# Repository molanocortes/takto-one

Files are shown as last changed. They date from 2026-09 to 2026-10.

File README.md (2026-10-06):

<div align="center">

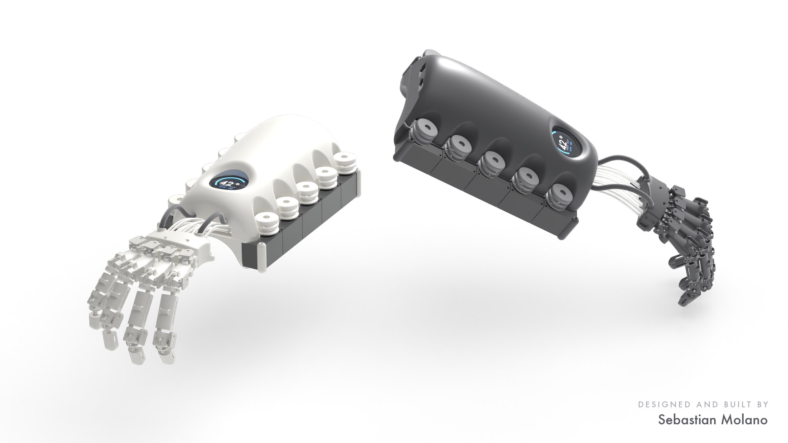
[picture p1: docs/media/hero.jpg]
TAKTO ONE


# TAKTO ONE

### Open hand control. Read every finger. Drive every finger.

TAKTO ONE is an open-source hand exoskeleton: it reads twelve finger joints at the joint
itself and pulls them back through tendons, with the control loop on the device, not on a laptop. Wear it and your hand becomes an
instrument: every motion measured, recorded, and answered with force. This repository is
every file needed to build one.

**[takto.one](https://takto.one)**, the official website: the device in 360°, the live digital
twin and the console, right in your browser.








</div>

---

<!-- The film: a poster image linking to a GitHub attachment URL. This is the ONE form that
     works on desktop web AND in the GitHub mobile app, verified 2026-09-04. How the others fail:
       - a <video> tag is stripped by GitHub's sanitiser everywhere; only what is inside survives
       - a bare user-attachments URL on its own line becomes an inline player on desktop web only;
         the mobile app renders it as a plain link
       - a relative link to the in-repo .mp4 opens the blob player on desktop, dead tap in the app
     The attachment is served as video/mp4 with no download disposition, so tapping plays natively.
     docs/media/TAKTO-ONE.mp4 is the durable in-repo copy (v057). The URL below was minted by
     dragging that file into a comment on PR #1 and POSTING the comment: attachments dragged in but
     never posted are garbage-collected, which is how the two previous URLs died. To update the film:
     replace the in-repo file, drag the new one (under 10 MB) into a comment on PR #1, post it,
     verify the URL logged out, then swap it here. -->

<div align="center">
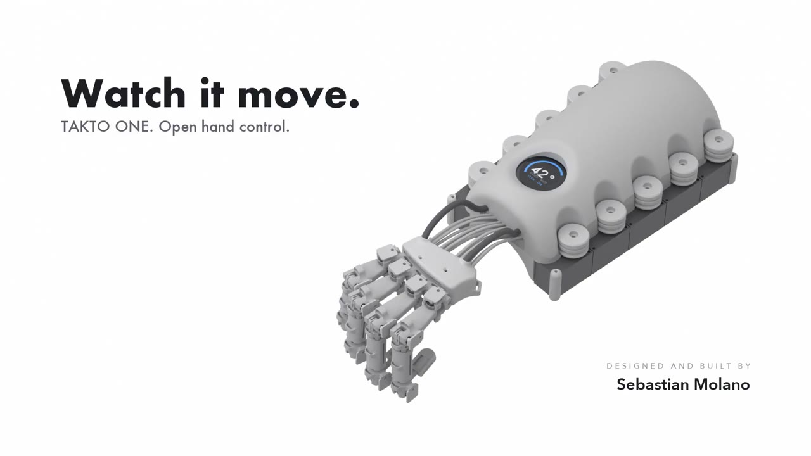
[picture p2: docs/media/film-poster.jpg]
Watch the film: TAKTO ONE turning in the white studio
  
</div>

---

<div align="center">

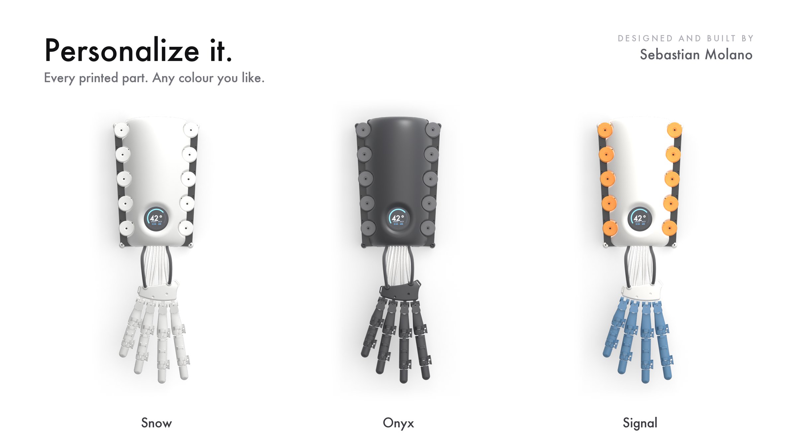
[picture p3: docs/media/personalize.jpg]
Personalize it, three colourways


</div>

---

## Why a hand, and why this one

Your hand is the highest-bandwidth interface you own, and machines still read it badly. A
camera loses fingers the moment they cross, curl, or leave frame. A glove full of flex sensors
drifts. TAKTO ONE puts a magnetic encoder on the joint itself, three per finger, twelve in
all, so the measurement ignores occlusion, lighting, and where you happen to stand. And
because the microcontroller owns the motor bus, the device acts without a computer in the loop.

Per-joint truth going in, tendon force coming out, no host required. It is a hand-shaped input
and output device, and what you point it at is up to you.

## What it already does

Two of the most useful things a hand platform can do are built and in this repository.

**Motion capture that writes to the device, not to a browser.** The firmware logs to the
Teensy's own SD card, one row per frame: all fourteen encoder channels, the hand, forearm and
thumb quaternions, EMG envelope and RMS, the crown, and full motor telemetry. One sensor
acquisition feeds the SD row, the serial stream and the display, so the log and the live view
can never disagree. The rate is a firmware constant, not a display refresh. The result is
serious hand-motion data: per-joint, occlusion-free, timestamped, labelled by physics instead
of by another model's guess.

**Teleoperation and assistance.** The control law runs on the Teensy in three modes: idle,
direct current, and a blend that moves continuously between *transparent*, where the device
follows the wearer and stays out of the way, and *assist*, where it drives toward a setpoint.
The blend is a live parameter, so the hand can lead the device, the device can lead the hand,
or anything in between. Setpoints, gains and current limits are all exposed over the serial
protocol, which is what lets one hand drive another.

Together they close the loop that matters: read a hand precisely, record it, and play it back
into a hand.

---

## Two custom boards

Designed from scratch in KiCad for this device and published in full: schematic, layout and
manufacturing outputs for each board are in [`electronics/`](electronics/). The renders come
straight from those files.

<table>
<tr>
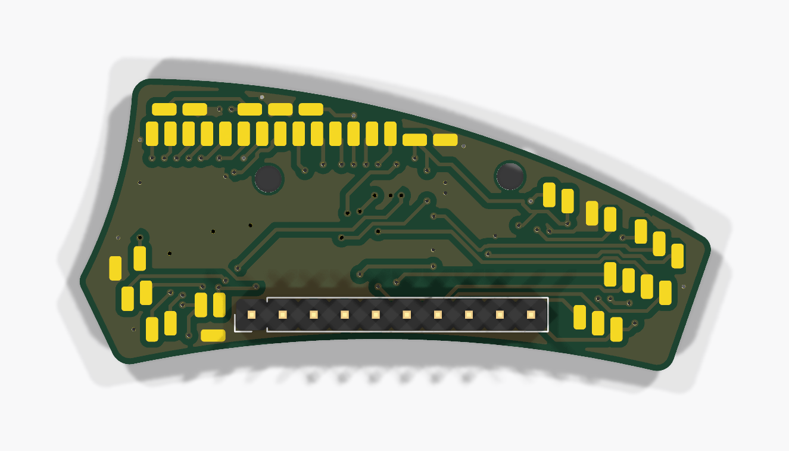
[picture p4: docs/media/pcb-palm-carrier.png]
Palm carrier board, KiCad 3D render
<td width="58%"></td>
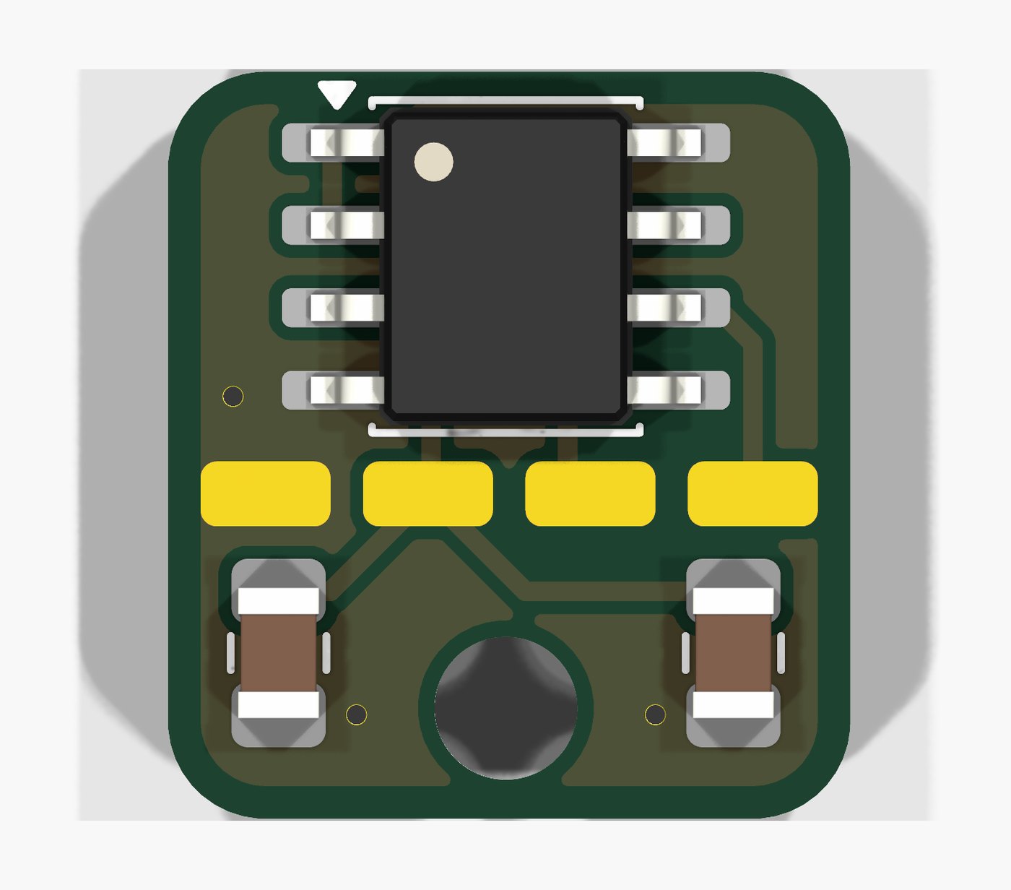
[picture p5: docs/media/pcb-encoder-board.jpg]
Encoder board, KiCad 3D render
<td width="42%"></td>
</tr>
<tr>
<td align="center"><b>Palm carrier</b></td>
<td align="center"><b>Encoder board</b></td>
</tr>
</table>

- **Palm carrier** (`palm_carrier/`). Shaped to the curved palm plate. Two TCA9548A I²C
  multiplexers fan the bus out to fourteen encoder channels: twelve joints, plus two reserved
  for a thumb.
- **Encoder board** (`encoder_board/`), one per joint. An AS5600 magnetic angle sensor centred
  under a through-board aperture, so the joint's magnet sits on the sensor's axis.

Both were fabricated and assembled in one JLCPCB order (June 2026, USD 170.73 delivered),
itemised in the [bill of materials](docs/BOM.md).
One known erratum, documented rather than hidden: on the palm carrier the second multiplexer's
SDA and SCL net labels are swapped on channels 8 to 13, so those six channels are wired
crossed. [`electronics/README.md`](electronics/README.md) has the detail. The 74HC241 servo-bus
interface is separate from these boards; its pins are in the firmware and in the wiring below.

## How it fits together

Sensing → aggregation → control → interface:

System architecture

And the full point-to-point wiring: every pin terminated, both I²C multiplexers, all fourteen
encoder channels, all three IMU positions, and the 74HC241 servo bus. The
[PDF](docs/global-wiring.pdf) is the printable version.

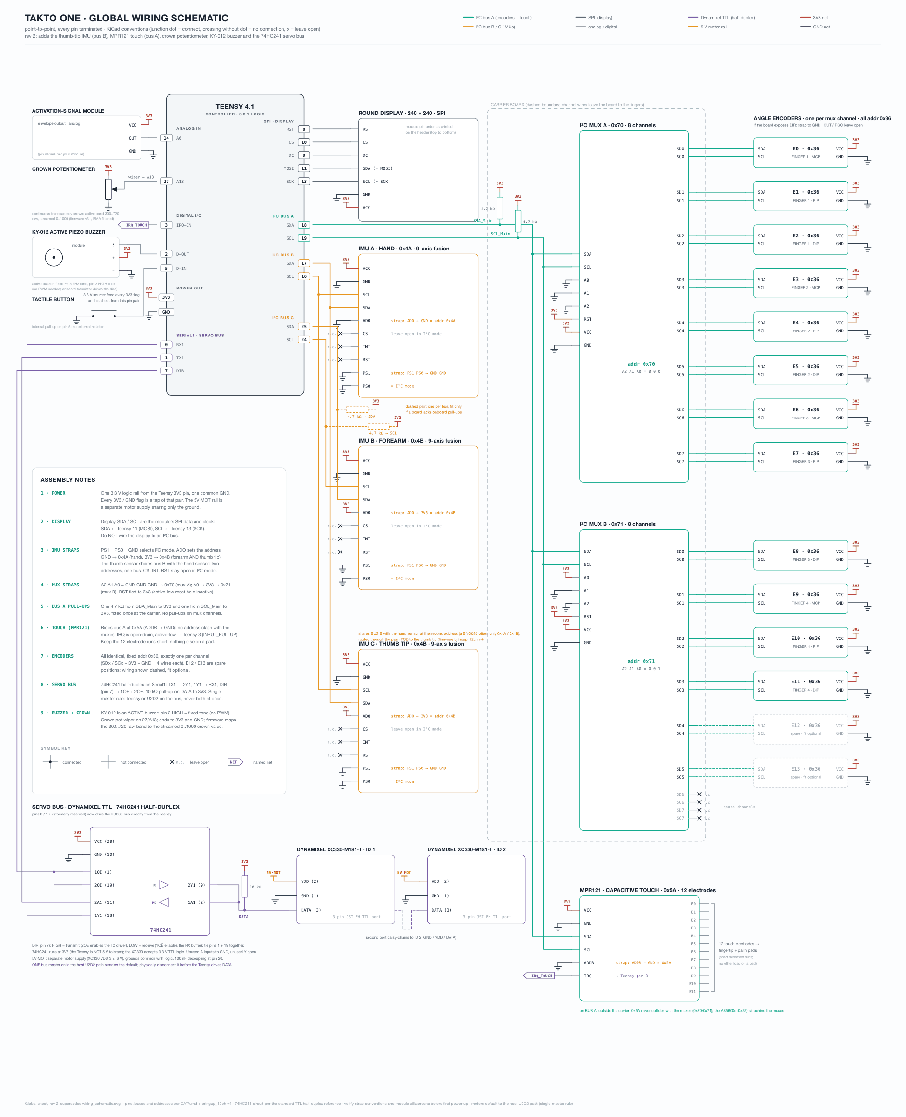
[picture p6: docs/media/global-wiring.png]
Global wiring schematic


---

## Session replay: motion, played back in space

Record a hand once and it replays anywhere the twin runs. The viewer rebuilds the session as a
4D scene: the real device GLB articulated by the twelve recorded joint angles, the wrist flying
the 6-DoF path the headset measured, the room drawn from the environment mesh stored with the
take, and the flexion and effort traces under the scrubber. Any speed, any angle, forever.

<!-- Loops on phones. GitHub loads every image in a README at once (it strips loading="lazy"),
     and the five GIFs on this page weigh 16 MB. The GitHub Android app also cannot show a README
     with a GIF in it: the page flickers on every frame and reads as empty (github.com/orgs/
     community/discussions/158337), and the app ignores <source>. So each loop is a <picture>
     whose <img> is a still frame (docs/media/<name>-still.*), which phones, the app and
     reduce-motion readers get, and whose <source> hands the GIF only to a wide screen with a
     mouse; a tap on the still opens the loop. Keep "prefers-color-scheme" out of that media
     query: GitHub's <themed-picture> rewrites any <source> that mentions it. -->

<div align="center">

<a href="docs/media/ui-replay.gif">
<picture>
  <source media="(min-width: 768px) and (pointer: fine) and (prefers-reduced-motion: no-preference)" srcset="docs/media/ui-replay.gif">
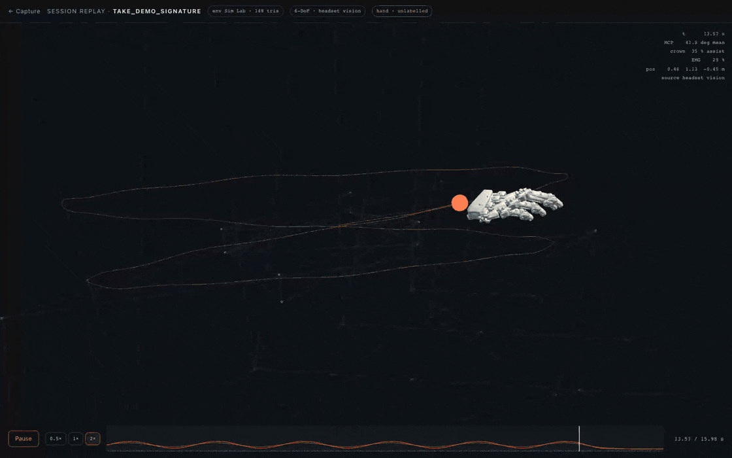
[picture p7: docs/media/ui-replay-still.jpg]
A recorded take replaying: the device hand banking along its full trajectory ribbon through a wireframe room, with live joint, effort and position read-outs
  
</picture>
</a>

<sub><b>take_demo_signature</b>, played at 2× in the shipped viewer. One of three sample takes
in [`software/bridge/samples/`](software/bridge/samples/) — choreographed, synthetic, and
generated by a script that ships beside them. Three commands and this plays on your machine
with no hardware.</sub>

</div>

The format is the same one the device writes to its SD card, so your own recordings drop
straight in. The environment store is wired end to end, but dense room reconstruction from the
Quest 3S is still open work: the viewer, the store and the upload path are all waiting for it,
and putting a real scanned room behind these trajectories is one of the most satisfying
contributions this project has to offer. See [Contributing](#contributing).

---

## LUMEN: the AR layer

**Source included:** [`software/ar/`](software/ar/)

A spatial layer that puts the hand twin and its data into the room instead of on a monitor.
It reads the same WebSocket stream as the console, needs no separate backend, and runs in a
plain browser on the desktop, which is how the frames below were captured.

<div align="center">

<a href="docs/media/ar-modes-live.gif">
<picture>
  <source media="(min-width: 768px) and (pointer: fine) and (prefers-reduced-motion: no-preference)" srcset="docs/media/ar-modes-live.gif">
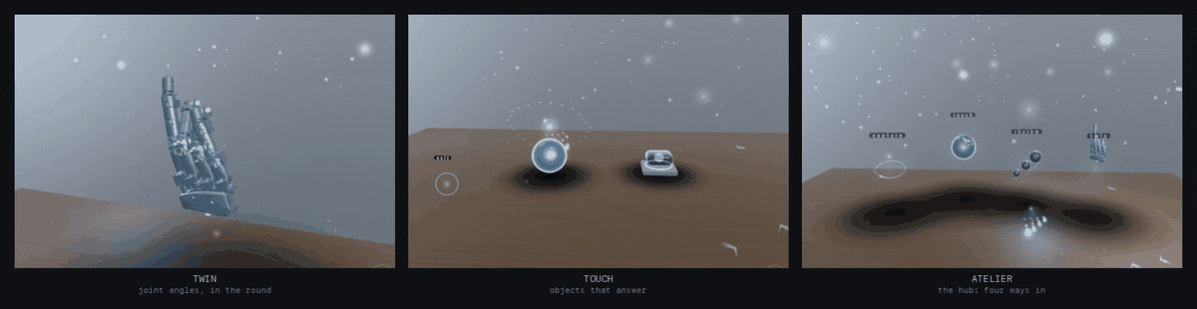
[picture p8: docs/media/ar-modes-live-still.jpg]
Three modes of the AR layer running: the hand twin seen from a moving viewpoint, a touch object deforming under contact, and the atelier hub with its four reachable objects
  
</picture>
</a>

<sub>Running live in the desktop preview: <b>twin</b>, the articulated hand driven by joint
angles and seen from a moving viewpoint &nbsp;·&nbsp; <b>touch</b>, objects that answer the wearer's fingers &nbsp;·&nbsp;
<b>atelier</b>, the hub, where the four modes are objects you reach toward rather than buttons.
Butterflies drift through every one of them.</sub>

</div>

Five modes ship: `atelier` as the hub, plus `twin`, `touch`, `rhythm` and `capture`. The scene
carries the device's own geometry, so what you reach toward is the machine on your arm. It is
also inhabited: butterflies wander the room, settle on the desk edge to rest their wings, and
lift off again, and rare comets cross the upper air. None of it competes with the work; it just
means the space is alive while you are in it.

> **Prototype, captured on the desktop preview** rather than in a headset. Known high-DPI bug:
> the render target is sized from CSS pixels while the canvas backs at the device ratio, so on
> a 2x display the scene draws into a quarter of the canvas. Force a device pixel ratio of 1 as
> a workaround; fixing it properly is a good first contribution.

---

## The phone companion

**Source included:** [`software/app/`](software/app/)

A pocket instrument for the times the laptop is not the right one: watch the twin, replay a
recorded session, and read the twelve joints and the activation channel, from the same stream
and protocol as everything else here. One Expo codebase for iOS, Android and the browser.

<div align="center">

<a href="docs/media/app-live.gif">
<picture>
  <source media="(min-width: 768px) and (pointer: fine) and (prefers-reduced-motion: no-preference)" srcset="docs/media/app-live.gif">
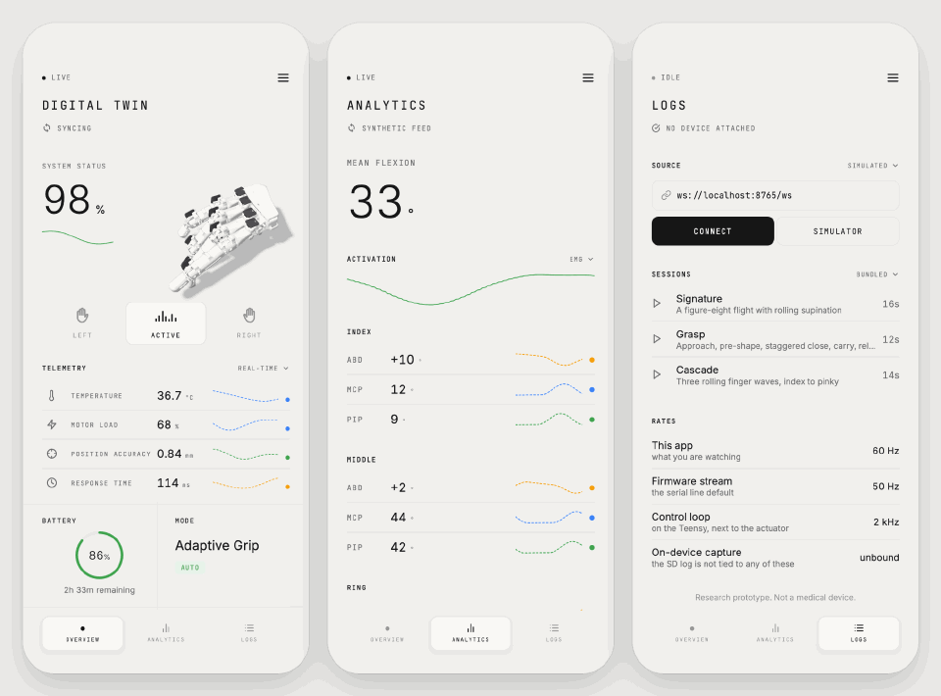
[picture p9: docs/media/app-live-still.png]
The companion app running: Overview, Analytics and Logs side by side on one clock, the twin curling finger by finger while the joint read-outs and the effort trace follow
  
</picture>
</a>

<sub><b>Overview</b>, the device at a glance &nbsp;·&nbsp; <b>Analytics</b>, the twelve joints and
the activation channel &nbsp;·&nbsp; <b>Logs</b>, the source, the bundled sessions and the rates</sub>

<sub>The travelling wave, index to pinky, on the synthetic feed. Twelve joints driven
independently, and all three surfaces pinned to the same clock: one instant of the app, not
three screens shot at three different moments.</sub>

</div>

The twin is the real CAD driven by the shared mechanical model in
[`kinematics.js`](software/app/src/data/kinematics.js): the angles, the telescopic slides those
angles demand, and the spool rotations that produce them. It runs with no hardware at all on
the same synthetic feed as every other surface, and the three bundled sessions are the
repository's own sample takes. Point it at a bridge and it reads a real device.

An earlier Android-only build is superseded by this one; its emulator captures are gone from
this page.

---

## The device screen

The Teensy drives a round display, and the face engine that paints it is part of the firmware.
One face ships, **thesis**, in three colourways (Sapphire Depth, Graphite and Amber), and it
covers every device state: battery, boot, calibrate, fault, idle, linked, recording, saved,
standalone, stop and teleop. Two earlier design studies, **rams** and **ferro**, stay in the
source for reference; they are not built into the firmware.

**None of these are static screens.** Every face animates: boot sweeps and self-tests, the
teleop ring tracking assist, the recording counter and its take meter, idle breathing while
nothing is happening. The engine runs a dirty-tile renderer inside a fixed frame budget, so the
paint never starves the control tick.

<div align="center">

<a href="docs/media/watch-faces-live.gif">
<picture>
  <source media="(min-width: 768px) and (pointer: fine) and (prefers-reduced-motion: no-preference)" srcset="docs/media/watch-faces-live.gif">
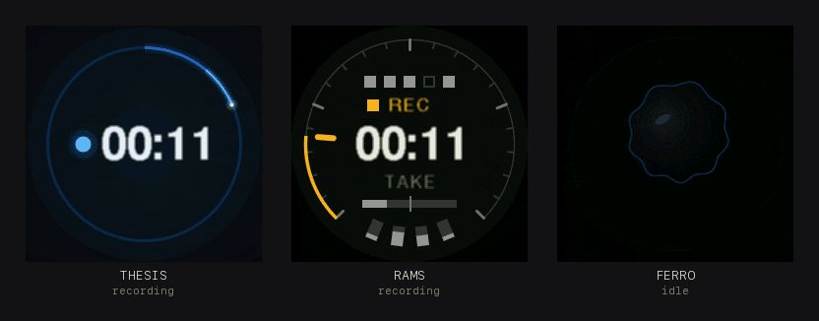
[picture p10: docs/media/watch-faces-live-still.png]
The thesis face and the two design studies animating: boot sequences, then recording counters and an idle face in motion
  
</picture>
</a>

<sub>Faces rendered by the firmware's own rasterizer from a mock feed and played at the speed
they were authored: the boot sequence of the shipping <b>thesis</b> face and of the two studies,
then <b>recording</b> counting a take up, and <b>idle</b> breathing.</sub>

</div>

<div align="center">

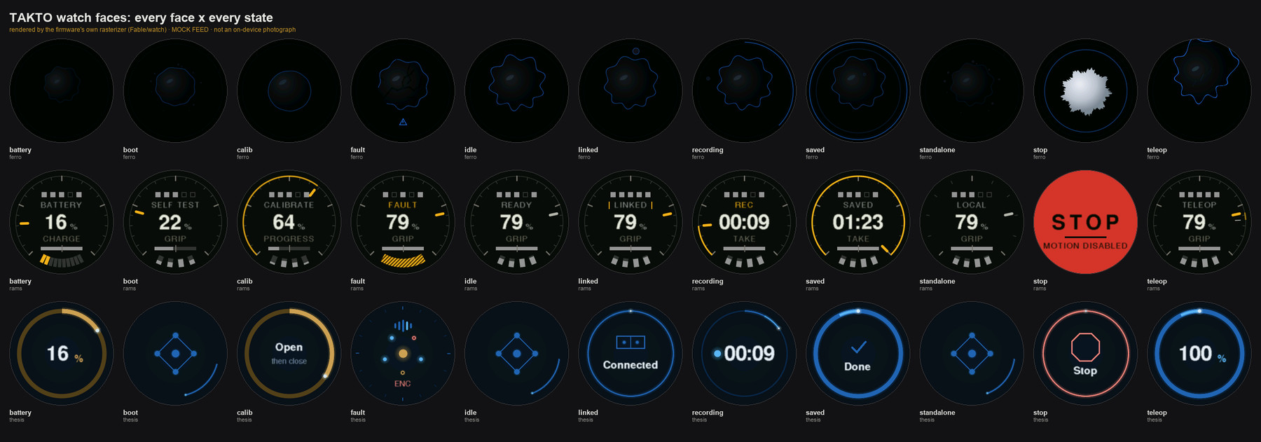
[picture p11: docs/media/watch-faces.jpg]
Three watch faces across every device state


<sub>The shipping face and the two studies against every state. These are renders, not
photographs of the physical screen.</sub>

</div>

The **thesis** face is the one the firmware builds. Source, the face engine, the frame budget
and the flashing runbook are in
[`firmware/takto_one/watch/`](firmware/takto_one/watch/).

---

## The website

**[takto.one](https://takto.one)** is the official home of TAKTO ONE, and its source is
[`software/web/`](software/web/) in this repository. One scrolling page: the device in three
finishes, the six parts that make it, the numbers behind it, a full 360° turn, and the live twin
and operator console, all in the browser and none of it needing hardware. Without a device the
console runs a clearly labelled simulation; it talks to a real TAKTO ONE only on your own
machine, and only when you connect it.

<div align="center">
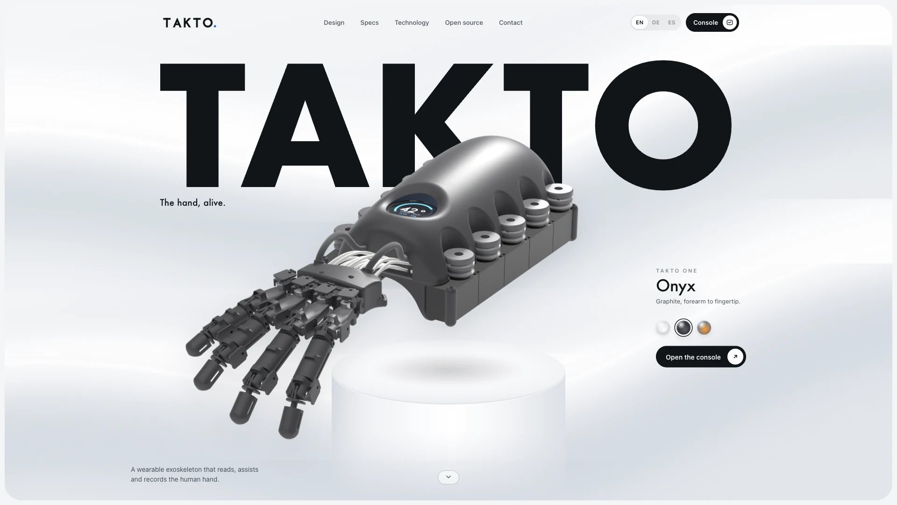
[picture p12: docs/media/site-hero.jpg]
takto.one: the TAKTO wordmark behind the graphite device floating over a white plinth

</div>

- **English, German and Spanish.**
- **Private by design.** No cookies, no analytics, no trackers. The camera modes ask before
  anything loads from a third party, and the video never leaves the browser.
- **Honest about its data.** Every view that shows the simulation says SIMULATED; nothing is
  labelled live unless a real device is delivering it.
- **Fast.** Served from Cloudflare's edge over HTTP/3. The console's code loads only when you
  open it, and the twin's 3D model is baked and compressed for the web.
- **One build script.** `node software/web/tools/build-site.mjs <outDir>` bundles, minifies and
  hashes the site into a folder any static host can serve (it uses `esbuild`, or fetches it with
  `npx`).

---

## The browser surfaces

There are four of them and they all read the same stream: the front end and the console
here, plus the AR layer and the phone companion above. None of them needs hardware.
Run the bridge with `--sim` and they animate on synthetic joints instead. What reaches the
browser is 60 Hz, which is a display rate and says nothing about how fast the device itself
runs (see [On rates](#a-note-on-rates)). Every twin renders the same articulated geometry
that ships in [`cad/`](cad/).

<!-- Poster linking to a posted GitHub attachment, for the reasons given at the film above.
     docs/media/TAKTO-SURFACES.mp4 is the durable in-repo copy; the URL was minted from the same
     PR #1 comment. Renders the same on desktop and in the mobile app. -->

<div align="center">
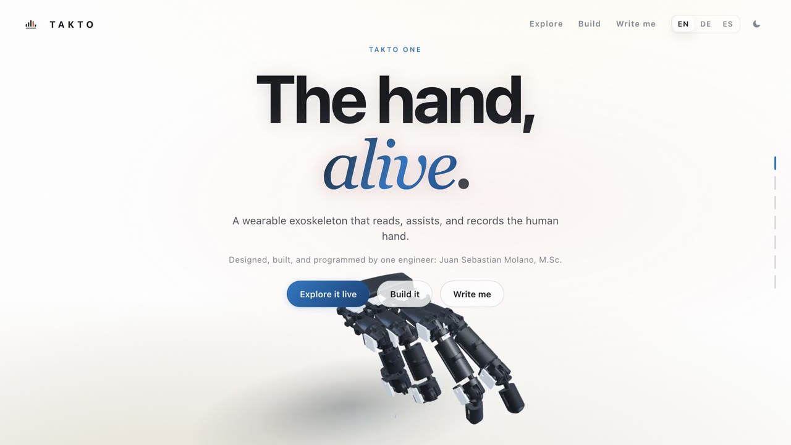
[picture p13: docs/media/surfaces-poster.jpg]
Watch the browser surfaces: front end, console, AR layer and phone companion
  
</div>

<div align="center">

<sub><b>The public front end.</b> A single scrolling page. The device turns and the fingers
move as you scroll, so each claim ends up beside the part of the machine it describes.<br>
<b>The operator console.</b> Live 3D twin, twelve per-joint encoders, motor state, EMG
effort, current draw, the device's own round screen, and calibration. Shown here on the
simulator, which is why the link says <i>mock</i>.</sub>

</div>

---

## EMG in the loop

Most hand devices sense position. TAKTO ONE also listens to the muscles.

The front end is a **MyoWare 2.0 muscle sensor** on a standard **three-lead setup**: two
electrodes along the target muscle belly and one reference on electrically quiet tissue, a
nearby bone or joint. The board does the analogue work — differential amplification of the two
muscle leads against the reference, rectification and envelope detection — and hands the
firmware a clean envelope on pin 14. The device carries the Ag/AgCl snap interface for it, so
it takes the same disposable gel electrodes used for ECG and EMG in clinical and lab work: skin
contact costs cents, not a custom part, and anyone can replace a pad mid-session.

The firmware oversamples that envelope at roughly 1 kHz between 50 Hz frames, reduces it to a
mean envelope plus RMS, and writes both into every frame of the stream and every row of the SD
log — on the same clock as the twelve encoders and the IMUs.

That single time base is the point. Encoders say what the hand did, IMUs say how it moved
through space, and EMG says what the wearer intended, fractions of a second before the joints
follow. Three signals, one clock: training data for models that learn intent, and a third
input for whoever builds the next control layer. The operator console and the public front end
both draw the live effort channel.

<div align="center">

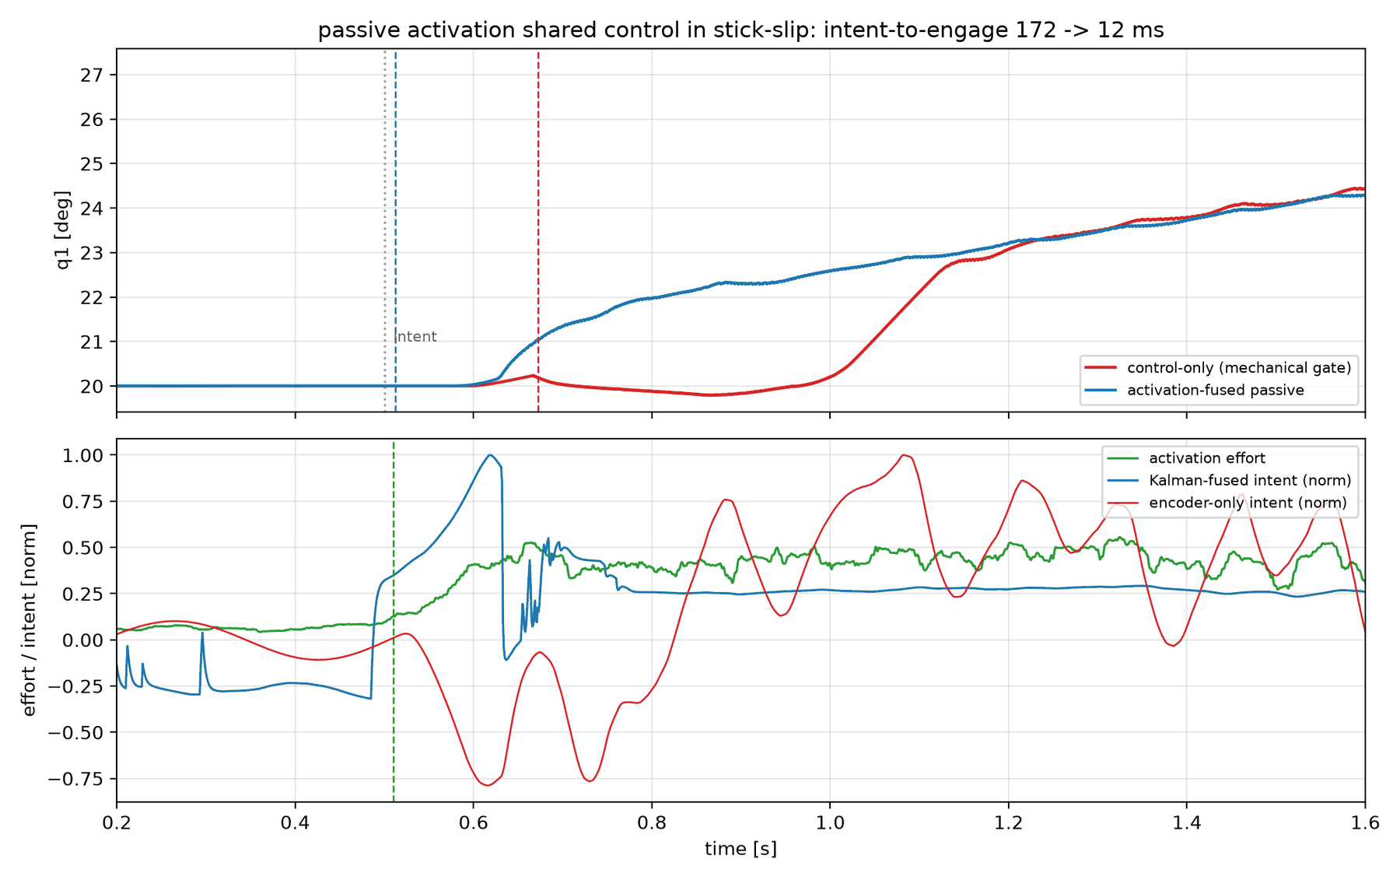
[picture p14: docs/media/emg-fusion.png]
Research figure: passive activation shared control in stick-slip, intent-to-engage improving from 172 to 12 ms when activation is fused with the encoder observer


<sub><b>Simulation</b>, from the project's intent-fusion research on a documented synthetic
signal model: in a stick-slip scenario the encoder-only observer takes 172 ms to engage assist;
fusing the activation channel cuts that to 12 ms, inside an energy-budgeted control law that
provably cannot drive motion on its own. Not a measurement on a person.</sub>

</div>

Behind that figure sits a research track in the wider project, not in this release: a causal
acquisition pipeline (band-pass, notch, RMS envelope), a whitened Bayesian decoder, and an
energy-tank shared-control law where activation leads the encoder during isometric loading
while a passivity certificate guarantees it can never self-drive the joint. Developed and
validated against a documented synthetic signal model with reproducible pass reports, and
stated as exactly that: signal-processing and control research, ready for hardware trials, not
claims about human experiments. If multi-source intent detection is your field, this device
was built to be your testbed.

---

## Sign language: a worked example

The clearest proof that this is a platform is **TAKTO-SIGN**: a German Sign Language capture,
training and live-recognition stack built on exactly this hardware. It records finger bend and
hand orientation at 60 Hz, learns a designed vocabulary, and recognises signs live. Like
everything else here, it runs end to end with no hardware through `--sim`.

Its scope statement is worth repeating because it is the right way to talk about work like
this: a **signer-dependent isolated-sign recogniser** with a continuous scripted-sentence path
and a measured cross-signer result. It is not open-vocabulary translation.

One application, built by one person, on this platform. An example of what the hardware
supports, not the limit of it.

## Where it can go from here

Read every finger and drive every finger, and a whole class of problems opens up. These are
**directions, not delivered features**; each is a project of its own, and open-sourcing the
platform is how they happen in parallel instead of one at a time. Every one of them starts
from the files already in this repository.

- **Drive a robot hand.** Per-joint angles map onto a robot hand with no camera rig and no
  capture volume. The exciting version is reach: a manipulator underwater, in a hot cell, or on
  another continent, driven by a hand that stays somewhere safe.
- **Train models on better data.** The capture above already produces clean per-joint ground
  truth. What is missing is scale: many hands, many tasks, a shared schema, a published
  dataset. That is community work.
- **Sign language.** Already begun. See [Sign language](#sign-language-a-worked-example).
- **Force feedback, per finger.** A tendon and a motor behind each finger means resistance that
  varies as you move: a surface that stops you, the give of soft tissue, the weight of a load,
  felt finger by finger instead of as one buzz through a handle. The control modes ship; the
  haptic rendering does not.
- **Rehabilitation and assessment.** Range of motion measured objectively across sessions, and
  assisted movement for a hand that cannot finish the motion alone.
- **Precision machine control.** Wherever a joystick is too blunt and a touchscreen impossible:
  gloved, wet, in the dark, eyes needed elsewhere.

Current status is stated plainly in [Where the project really stands](#where-the-project-really-stands).

---

## The machine

<a href="docs/media/turntable.gif">
<picture>
  <source media="(min-width: 768px) and (pointer: fine) and (prefers-reduced-motion: no-preference)" srcset="docs/media/turntable.gif">
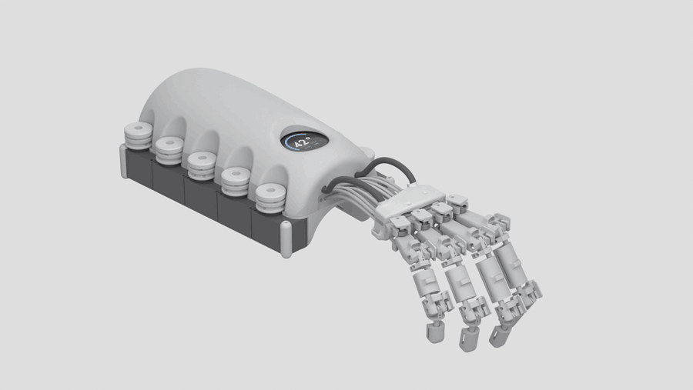
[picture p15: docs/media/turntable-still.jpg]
TAKTO ONE, one full turn
  
</picture>
</a>

| | |
| --- | --- |
| **Mechanism** | Tendon-driven, four instrumented long-finger assemblies |
| **Actuation** | Series-elastic, through elastic tendons and ratchet-based spools |
| **Joint sensing** | 12 × AS5600 magnetic encoders, 3 per finger |
| **EMG** | Embedded Ag/AgCl electrode interface for standard snap gel electrodes; envelope + RMS in every frame |
| **Controller** | Teensy 4.1 |
| **Motor bus** | Dynamixel Protocol 2.0 over a 74HC241 half-duplex interface, **the microcontroller owns the bus; no host PC required** |
| **Electronics** | 2 custom PCBs, full KiCad sources + manufacturing outputs |
| **Interface** | Browser operator console with a live 3D twin, over a serial→WebSocket bridge |
| **Structure** | 3D printed; as built, a mix of PETG and PLA |
| **Parts** | 71 printed parts, 8 servos, 12 encoder boards as designed. Full [bill of materials](docs/BOM.md) |

---

## What it costs to build

Eight motors, twelve instrumented joints, seventy-one printed parts. The servos are nearly the
whole bill; every other group put together is under a fifth of it, which is why cutting the
motor count is the most useful thing anyone could contribute.

<div align="center">
  <picture>
    <source media="(prefers-color-scheme: dark)" srcset="docs/media/bom-cost-dark.svg">
    Parts cost by group: actuation EUR 1040 of a EUR 1222.25 total, then print stock 50.00, motion sensing 44.38, control 43.97, joint sensing 26.40, transmission 17.50
  </picture>
</div>

Part numbers, suppliers, quantities and the caveats are in **[`docs/BOM.md`](docs/BOM.md)**,
with a machine-readable copy in [`docs/bom.csv`](docs/bom.csv).

---

## Start here

Clone to a moving hand in under a minute: the console opens in simulation, so you can explore
the whole stack before you print a single part. (No clone needed just to look around:
[takto.one](https://takto.one) runs the same twin and console in your browser.)

```bash
git clone https://github.com/molanocortes/takto-one.git
cd takto-one

# see the console and 3D twin immediately, no hardware needed
python3 -m http.server 8096 --directory software/console/app
# open http://localhost:8096/
```

Then read [`docs/README.md`](docs/README.md): system architecture, the illustrated build
guide, and the known corrections between the documentation and the current hardware.

| Step | Where |
| --- | --- |
| Source the parts | [`docs/BOM.md`](docs/BOM.md) |
| Choose and print parts | [`cad/README.md`](cad/README.md) |
| Order and wire the boards | [`electronics/README.md`](electronics/README.md) |
| Flash the Teensy | [`firmware/README.md`](firmware/README.md) |
| Connect the twin to hardware | [`software/README.md`](software/README.md) |

The embedded Dynamixel driver is also maintained standalone as
[**dynamixel-on-device**](https://github.com/molanocortes/dynamixel-on-device).

## Where the project really stands

Precision here matters more than a longer feature list.

**Verified on hardware.** The firmware runs on the device. The Teensy owns the Dynamixel bus
through the 74HC241 and drives one finger with two XC330 servos: motor-controlled finger
movement was demonstrated and tested on the bench, with the transmission run both with and
without its elastic element in series. The full design takes eight servos; the other six are
not fitted yet. All twelve magnetic encoders have read live together on the worn device and fed
the browser twin in real time. Two BNO085 IMUs are fitted, on the hand and the forearm. Four
long-finger assemblies are built and instrumented, and both PCBs exist as manufactured designs
with complete sources.

**On the bench today (October 2026).** After a wiring fault, four encoder channels (00, 04, 05
and 11: the middle finger and the ring finger's abduction) answer nothing on I²C, so eight of
the twelve joints read live until the harness is repaired. The fault is in the wiring, not the
firmware.

The firmware and the wiring carry a third IMU channel for a thumb-tip unit that is **not
fitted**, in the same way the two multiplexers carry fourteen encoder channels for twelve
populated encoders. The unfitted channel reports MISSING in the `s` bus scan, streams a live
flag of zero, and logs an identity quaternion, so nothing downstream mistakes it for data.

**Not established by this repository.** Force rendering, transparency control, and assistance
behavior are not characterized by measurements here. Verify the actuator count, limits, and
safety behavior on your own hardware before any worn experiment.
Repository-preparation checks are in the [verification record](docs/RELEASE_VERIFICATION.md).

**Known limitations.** Eight motors makes this an expensive build. The series-elastic
actuation is a simple implementation, elastic tendons and ratchet spools, not an advanced SEA
design. Recent soft-robotics work achieves comparable sensing with simpler mechanisms. This is
a working, well-instrumented research platform, not a claim to the state of the art, and those
gaps are exactly where contributions help most.

### A note on rates

Loop rate, sampling rate, telemetry rate and console update rate are four different numbers;
collapsing them into one is the easiest way to mislead someone.

- **Browser console: 60 Hz.** Snapshot broadcast to connected browsers. A display rate.
- **Firmware streaming default: 50 Hz.** `SAMPLE_HZ` in the sketch in this release, the
  serial-line rate. The development firmware, not yet released here, streams 100 Hz; that is
  the figure on takto.one.
- **Embedded control loop: up to 2 kHz.** The control law runs on the Teensy, next to the actuator.
- **On-device capture is bound by none of the above.** The streaming rate is a firmware
  constant, and logging can run considerably faster than what the console displays.

The ceiling on encoder sampling is set by the I²C bus and multiplexer switching, and it has
not been characterised here. If your application depends on a specific rate, measure it on
your own build.

## Safety

> TAKTO ONE is an experimental research prototype. **It is not a medical device and not a
> certified protective product.** Do not use it for diagnosis, treatment, unsupervised
> rehabilitation, or safety-critical operation.

Keep actuator power independently removable, begin with torque disabled, test away from the
body, confirm mechanical limits, and validate watchdog and fault behavior before any worn
experiment.

## Contributing

This project is under active development and contributions are genuinely wanted. The
limitations above are not fine print; they are the to-do list, and some of the most
interesting problems are still unclaimed.

- **Build one**, and tell us what was unclear, what did not fit, what you changed. Build
  reports are the single most valuable contribution.
- **Improve the actuation.** The current transmission runs on the bench with and without its
  elastic element in series; a better series-elastic design is the most interesting open
  problem here.
- **Reduce the motor count.** Eight is expensive; underactuation would widen who can build this.
- **Build the thumb.** The forearm carries ten spool bays and only eight are used, so the room
  for a thumb pair is already in the mechanism, and the firmware already addresses two spare
  encoder channels. A thumb's linkage, tendon routing and kinematics are yours to invent;
  the fingers' already exist and work.
- **Scan the room.** The replay viewer, the environment store and the upload path are wired
  end to end; dense room reconstruction from the Quest 3S is the missing piece. Make a real
  room appear behind the trajectories and session replay becomes a spatial lab notebook.
- **Fix documentation.** Known deltas are listed in [`docs/README.md`](docs/README.md); find more.
- **Firmware, bridge, console.** Bugs, features, and platform ports.

See [`CONTRIBUTING.md`](CONTRIBUTING.md). Open an issue with questions, ideas, or photos of
your build; showing what you made is always welcome. For anything that does not belong in a
public issue, write to [sebastianmolano.eng@gmail.com](mailto:sebastianmolano.eng@gmail.com).

## License

Software **Apache-2.0** · Hardware **CERN-OHL-S-2.0** · Documentation and media **CC-BY-4.0**.
Full detail, attribution format, and the text-and-data-mining reservation: [`LICENSE.md`](LICENSE.md).

The hardware licence is strongly reciprocal: distribute a modified design and you publish your
modifications. If that does not suit your situation, licensing on other terms is available,
see [`LICENSE.md`](LICENSE.md). Contributors are asked to agree to a short [CLA](CLA.md), which
keeps relicensing possible and leaves your copyright with you.

**TAKTO and TAKTO ONE are trademarks of Sebastian Molano**, asserted as unregistered marks and
not covered by any licence above. Build it, change it, sell it, and say it is based on TAKTO
ONE; just give your own version its own name. Details in [`LICENSE.md`](LICENSE.md).

<div align="center">
<sub>Designed and built by Sebastian Molano · Hochschule Anhalt · Made in Germany<br>
<a href="mailto:sebastianmolano.eng@gmail.com">sebastianmolano.eng@gmail.com</a></sub>
</div>

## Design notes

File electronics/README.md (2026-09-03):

# Electronics

This folder contains the two custom PCB designs used by TAKTO ONE.

- `encoder_board/` is the AS5600 magnetic encoder board.
- `palm_carrier/` is the palm sensor carrier and TCA9548A multiplexer board.

Each board includes its KiCad source and the matching manufacturing outputs. The checked-in sources match the working project copies used for this release.

The current embedded motor architecture uses a separate 74HC241 half-duplex interface on Teensy `Serial1`, with direction control on pin 7. That interface is not integrated into the published palm-carrier Gerbers. Do not infer motor-bus wiring from the PCB files alone; use the pin map in `firmware/takto_one/takto_one.ino` and verify the buffer truth table, voltage domains, common ground, and receive-default state on the bench.

## Wiring note: palm carrier channels 8-13

The second multiplexer (`U2`) on the palm carrier has its `SDA`/`SCL` net labels transposed on
all six channels it uses. When wiring channels 8-13, connect your sensor's `SCL` to the pad
marked `SDA` and its `SDA` to the pad marked `SCL`. The first multiplexer (`U1`, channels 0-7)
is correct as labelled. Routing and silkscreen are otherwise correct; this affects net naming
only. Full detail in [`../docs/README.md`](../docs/README.md).

Before ordering, open both projects in KiCad, update footprints only deliberately, and run ERC/DRC plus an independent manufacturing review. The manufacturing files are provided as the project outputs, not as a guarantee from a board house.

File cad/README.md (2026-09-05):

# Mechanical CAD

These files were exported directly from Autodesk Fusion on 2026-08-27 from the current cloud state of `Zero_Final_Assembly_Complete` version 35. Fusion reported no out-of-date child references.

- `stl/` contains high-resolution binary meshes in millimetres for slicing and inspection.
- `step/` contains isolated solid bodies for neutral CAD interchange and editing.

The source assembly also contains third-party reference models and a hidden personal arm scan. Those items, and the complete unfiltered assembly archive, are intentionally not published, **with one deliberate exception**: `base_spool` is an adaptation of a third-party part from the ORCA hand project and is published here with the attribution its CC BY 4.0 licence requires. See [`THIRD_PARTY_NOTICES.md`](../THIRD_PARTY_NOTICES.md). Every STEP file was created from an isolated TAKTO-authored body so it does not carry the unpublished references.

## Export manifest

Quantities are occurrences in the designed assembly, not a validated procurement or print plan.

| Fusion component | Cloud version | Quantity | Files |
| --- | ---: | ---: | --- |
| `BaseSpool` | 5 | 10 | STL only; Fusion source is mesh-only. **Adapted from the ORCA hand project, CC BY 4.0**, see [`THIRD_PARTY_NOTICES.md`](../THIRD_PARTY_NOTICES.md) |
| `SpoolCover` | 6 | 10 | STL, STEP |
| `Zero_Corners` | 9 | 4 | STL, STEP |
| `Zero_Finger2_Knuckle_Thin_V3` | 7 | 3 | STL, STEP |
| `Zero_Finger2_Knuckle_V3` | 13 | 4 | STL, STEP |
| `Zero_Finger2_MCP_Center_V3` | 18 | 2 | STL, STEP |
| `Zero_Finger2_MCP_Thick_V3` | 22 | 2 | STL, STEP |
| `Zero_Finger2_MCP_Thin_V3` | 9 | 2 | STL, STEP |
| `Zero_Finger2_PIP_Center_V3` | 12 | 4 | STL, STEP |
| `Zero_Finger2_PIP_Thin_V3` | 14 | 4 | STL, STEP |
| `Zero_Finger3_Knuckle_Thin_V3` | 5 | 1 | STL, STEP |
| `Zero_Finger4_MCP_Center_V3` | 8 | 1 | STL, STEP |
| `Zero_Finger4_MCP_Thick_V4` | 1 | 1 | STL, STEP |
| `Zero_Finger4_MCP_Thin_V4` | 1 | 1 | STL, STEP |
| `Zero_Finger5_MCP_Center_V3` | 6 | 1 | STL, STEP |
| `Zero_Finger5_MCP_Thick_V4` | 2 | 1 | STL, STEP |
| `Zero_Finger5_MCP_Thin_V4` | 1 | 1 | STL, STEP |
| `Zero_Forearm_Part2_V1` | 151 | 1 | STL, STEP |
| `Zero_Forearm_V5` | 67 | 1 | STL, STEP |
| `Zero_Generated3` | 6 | 1 | STL, STEP |
| `Zero_Generative1` | 9 | 3 | STL, STEP |
| `Zero_Heels` | 1 | 1 | STL, STEP |
| `Zero_Palm_Cap_V3` | 18 | 1 | STL, STEP |
| `Zero_Palm_V3` | 39 | 1 | STL, STEP |

A full build also needs the ratchet, one per spool station. It is a third-party part and lives in [`third_party/orca/`](third_party/orca/) under CC BY 4.0, separate from the CERN-OHL-S-2.0 geometry in `stl/` and `step/`.

The physical prototype contains both PETG and PLA parts. Material, orientation, supports, tolerances, and fasteners must be selected and verified for the intended build; this release does not claim one universal print profile.

## How it goes together

The STEP and STL files above are isolated parts. The assembly is documented, but not in this
folder, and a builder who lands here first has missed it: the **24-page illustrated build guide**
at [`../docs/build-guide.pdf`](../docs/build-guide.pdf) walks the whole device in order, with
1:1 part-check plates on the last page. Read [`../docs/README.md`](../docs/README.md) beside it:
two of the guide's statements (U2D2 on the motor bus, 100 % PETG) are superseded and the
corrections are listed there. Everything mechanical in the guide reflects the device as built.

| Guide chapter | Pages | What it assembles |
| --- | ---: | --- |
| Build one finger | 3 to 8 | MCP link, knuckle, root bearings, PIP link, three magnets, three encoder boards |
| Forearm housing and electronics | 9 to 14 | Shell, corner pillars, ten servos, deck, Teensy plate, display, IMU, EMG |
| A tendon spool bay | 15 | Spool, ratchet, cover, one of ten |
| Palm stack | 16 to 18 | Palm, carrier board, spacers, IMU, cap |
| Wiring and soldering | 19 to 22 | Every run cut to length, and the carrier pad each one lands on |
| Part-check plates | 24 | Print at 100 %, lay each part on its outline |

### Reading the filenames

Fingers are numbered as anatomical digits, so the thumb would be 1 and **`finger2` is the
index, `finger3` the middle, `finger4` the ring, `finger5` the little finger**. The finger
chapter is drawn for the index and the other three follow the same sequence.

A `finger2` prefix does not always mean index-only. The quantities in the export manifest above
say what is shared:

| Part in the guide | File | Used by |
| --- | --- | --- |
| MCP link, thick half | `zero_finger2_mcp_thick_v3` | index and middle |
| | `zero_finger4_mcp_thick_v4` | ring |
| | `zero_finger5_mcp_thick_v4` | little |
| MCP centre piece | `zero_finger2_mcp_center_v3` | index and middle |
| | `zero_finger4_mcp_center_v3` | ring |
| | `zero_finger5_mcp_center_v3` | little |
| MCP link, thin half | `zero_finger2_mcp_thin_v3` | index and middle |
| | `zero_finger4_mcp_thin_v4` | ring |
| | `zero_finger5_mcp_thin_v4` | little |
| Knuckle base | `zero_finger2_knuckle_v3` | all four |
| Knuckle plate | `zero_finger2_knuckle_thin_v3` | index, ring, little |
| | `zero_finger3_knuckle_thin_v3` | middle |
| PIP link | `zero_finger2_pip_thin_v3` | all four |
| PIP centre piece | `zero_finger2_pip_center_v3` | all four |
| Palm, palm cap | `zero_palm_v3`, `zero_palm_cap_v3` | one each |
| Forearm shell, in two parts | `zero_forearm_v5`, `zero_forearm_part2_v1` | one each |
| Corner pillars | `zero_corners` | four |
| Spool, ratchet, cover | `base_spool`, [`third_party/orca/Ratchet.stl`](third_party/orca/), `spool_cover` | one set per bay, ten bays |
| Deck and supports | `zero_generative1` (3), `zero_generated3`, `zero_heels` | forearm chapter |

Hardware that is not printed, all on the part-check plate: MR84-2Z bearings (4 x 8 x 3 mm, two
per MCP), 2 x 5 x 2.5 mm bearings (two per PIP), 4 x 2 mm **diametrically** magnetised magnets
(three per finger, orientation matters), 2 mm guide rods (13.2 mm at the MCP, 16 mm at the
PIP), and the M2, M2.5 and M3 screws listed with counts on page 24.

### The assembly files

The parts above are isolated. **How they sit relative to each other is a separate download,
attached to the [v1.0.0 release](https://github.com/molanocortes/takto-one/releases/tag/v1.0.0)**
rather than committed, so cloning this repository stays cheap:

| File | Contents |
| --- | --- |
| `TAKTO-ONE_Finger_Index.f3d` / `.step` | A complete finger: both MCP halves and centre, knuckle base and plate, PIP link and centre, three encoder boards, two bearings |
| `TAKTO-ONE_Finger_Middle` / `_Ring` / `_Little` | The same sequence at each finger's link lengths |
| `TAKTO-ONE_Palm_Stack.f3d` / `.step` | Palm, carrier board, spacers, palm IMU, cap |
| `TAKTO-ONE_Part_Sources_f3d.zip` | **Every part above as a Fusion native**, 29 files, named to match `stl/` and `step/` here. This is the source in the preferred form for modification: open one, change a dimension, re-export your own STL |

The individual part sources are the ones to take if you intend to change something: STEP and STL
are dead geometry, while each `.f3d` carries its own sketches, parameters and feature history.

**Open the `.f3d` in Fusion if you can.** It carries the real component names from the manifest
above, the parametric history and the joints, and it is the source in the preferred form for
modification that CERN-OHL-S-2.0 asks for. The `.step` files open anywhere and their geometry and
positions are exact, but because these parts are external references in Fusion, STEP export names
its products after internal reference IDs rather than component names: expect entries like
`2026-05-22-23-42-25-476` in the tree. Right geometry, unhelpful labels.

**The forearm assembly is not included.** Its Fusion assembly contains manufacturer and community
CAD of purchased parts (servos, Teensy, display, U2D2, MyoWare, JST connectors) that are not this
project's to redistribute. Every TAKTO-authored forearm part is already above as an individual
file, and the build guide covers the forearm on pages 9 to 14 and a spool bay on page 15. A
personal arm scan used as a fitting reference is likewise excluded, and verified absent from every
published file.

### Purchased parts, and where their CAD comes from

Vendor and community models are not redistributed here. To complete the assembly on your own
machine, take them from the source:

| Part | Source for the model |
| --- | --- |
| Dynamixel XC330-M181-T | ROBOTIS e-Manual, product page downloads |
| Teensy 4.1 | PJRC publishes dimensions; community STEP models exist on GitHub |
| GC9A01 1.28" round display | Module vendor, varies by supplier |
| BNO085 breakout, AS5600 board | Breakout vendor, or model the outline from the datasheet |
| MR84-2Z bearing, 2 x 5 x 2.5 bearing | Any bearing manufacturer's catalogue, standard sizes |
| MyoWare 2.0 | SparkFun |

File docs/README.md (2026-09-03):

# Documentation

| Document | What it covers |
| --- | --- |
| [`system-architecture.svg`](system-architecture.svg) | Sensing, aggregation, control, and host layers as one diagram |
| [`global-wiring.pdf`](global-wiring.pdf) | Full point-to-point wiring: every pin terminated, both I²C multiplexers, all encoder channels, three IMUs, and the 74HC241 servo bus. Rendered inline in the top-level README as [`media/global-wiring.png`](media/global-wiring.png) |
| [`BOM.md`](BOM.md) | Bill of materials for the costed four-finger configuration: parts, quantities, suppliers, and dated indicative prices. Machine-readable copy in [`bom.csv`](bom.csv) |
| [`build-guide.pdf`](build-guide.pdf) | 24-page illustrated assembly walkthrough, including 1:1 part-check plates |
| [`RELEASE_VERIFICATION.md`](RELEASE_VERIFICATION.md) | How this release was assembled and checked |

## Build notes and corrections

Read these alongside the documents above. They are the known deltas between the written
documentation and the current hardware and firmware.

### I²C channel labels on the palm carrier, channels 8–13

On the palm carrier, the second multiplexer (`U2`) has its `SDA`/`SCL` net labels transposed
on all six channels it uses. The nets named `SDA8`–`SDA13` land on that device's clock pins,
and `SCL8`–`SCL13` land on its data pins.

**When wiring channels 8–13, swap the two signal wires relative to the label:** connect your
sensor's `SCL` to the pad marked `SDA`, and its `SDA` to the pad marked `SCL`. The first
multiplexer (`U1`, channels 0–7) is labelled correctly and needs no change.

This is a net-naming error only. The routing, the silkscreen positions, and the board itself
are otherwise correct, and the firmware works against the hardware as built once the six pairs
are wired as described.

### The build guide predates the current motor architecture

The build guide was written during the thesis work and two of its statements have since been
superseded:

- It states that the motor bus is owned by a host PC through a U2D2 and that the Teensy only
  senses. **This is no longer the case.** The Teensy 4.1 owns the Dynamixel bus directly
  through a 74HC241 half-duplex interface; a host PC is optional. See the top-level README and
  [`dynamixel-on-device`](https://github.com/molanocortes/dynamixel-on-device).
- It describes the prototype as 100% PETG. The as-built prototype uses **both PETG and PLA**.

Everything else in the guide, the mechanical assembly order, part-check plates, tendon
routing, spool and ratchet setup, and board fitting, reflects the device as built.

### The ratchet is a third-party part

The actuation uses ratchet spools, and the ratchet itself is not TAKTO-authored. It is ORCA's
`Ratchet.stl`, redistributed unmodified at
[`cad/third_party/orca/`](../cad/third_party/orca/) under CC BY 4.0, **not** under this
project's CERN-OHL-S-2.0. Print one per spool station, ten for a full build. That folder carries
the licence text, the attribution, and a SHA-256 you can check against upstream.

The mating `cad/stl/base_spool.stl` in this release is a TAKTO-modified adaptation of ORCA's
`BaseSpool.stl` and *is* included; `cad/stl/spool_cover.stl` is TAKTO's own design and is not
interchangeable with ORCA's `SpoolCover.stl`. See
[`THIRD_PARTY_NOTICES.md`](../THIRD_PARTY_NOTICES.md).

### Board revision

The wiring documentation cites carrier nets from a `Zero_Palm_V2` schematic. The KiCad project
published here is `Zero_Palm_V1`. Treat the published KiCad sources as authoritative for pad
and net questions, and the wiring PDF as the routing overview.

### Motor bus is not on the published Gerbers

The 74HC241 half-duplex interface is wired separately on Teensy `Serial1` with direction
control on pin 7. It is not integrated into the published palm-carrier Gerbers. Use the pin map
in `firmware/takto_one/takto_one.ino` and verify the buffer truth table, voltage domains,
common ground, and receive-default state on the bench.

## Notes on the bundled website

The website in `software/web/` is the source of the public front end, with one deliberate
omission: **`assets/docs/` is not included.** In the working copy that folder holds private documents that are not
distributed here. A preprint call-to-action that pointed into it was removed along with it. Add
such a link back only when there is a published paper to point at, and prefer a DOI to a bundled
PDF.

The page also probes for three optional files and simply hides the corresponding element when
they are absent: `assets/cv.pdf`, `assets/vision.jpg` and `assets/film/poster.jpg`. If you drop a
CV at that path in a public fork, it becomes public with everything in it. That is worth knowing
before you use it.

The AR layer in `software/ar/` is the app only. Its capture and asset tooling is not included.
It also has a known bug on high-DPI displays: it sizes its render target from CSS pixels while
the canvas backs at the device ratio, so on a 2x screen the scene draws into a quarter of the
canvas. Force a device pixel ratio of 1 as a workaround.

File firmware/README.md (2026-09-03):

# Firmware

`takto_one/` is the unified Teensy 4.1 firmware. The checked-in sketch reports firmware version 15 and includes:

- Up to 14 AS5600 channels through two TCA9548A multiplexers
- BNO085 support across the configured I²C buses
- EMG-envelope input, SD recording, crown/button/piezo input, and a GC9A01A display
- A production TAKTO watch face
- Two-motor Dynamixel Protocol 2.0 support through a 74HC241 on `Serial1`
- Torque-off startup, bus fault accounting, communication watchdogs, and bounded control modes

## Build

Install the Teensy board package and the Adafruit GFX and Adafruit GC9A01A libraries, then open `takto_one/takto_one.ino` in Arduino IDE and select **Teensy 4.1**.

From an Arduino IDE installation that bundles `arduino-cli`, the equivalent compile is:

```bash
arduino-cli compile --fqbn teensy:avr:teensy41 --libraries "$HOME/Documents/Arduino/libraries" firmware/takto_one
```

The BNO085 and Dynamixel drivers used by this sketch are included locally. The full pin map, serial stream, command menu, and motor commands are documented at the top of `takto_one.ino`.

## Bring-up order

Compile first, then verify sensing, display, storage, and the serial stream with motor power disconnected. Test the 74HC241 receive-default state and single-master rule before taking the Dynamixel bus. Enable torque only with the mechanism clear, an independent power cutoff available, and feedback confirmed.

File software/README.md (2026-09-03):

# Software

Five surfaces sit on one data path. All of them run against a simulated device, so the whole
stack can be explored before a single part is printed.

| Folder | What it is |
| --- | --- |
| [`console/`](console/) | The operator console: live 3D twin, per-joint encoders, motor state, EMG effort, calibration. Defaults to a built-in simulated source, so it opens with no hardware and no bridge. |
| [`web/`](web/) | The project's public front end plus the app routes behind it, including the capture library and the 4D session replay. Three locales. Ships without `assets/docs/`; see [`../docs/README.md`](../docs/README.md). |
| [`ar/`](ar/) | The WebXR layer: the worn hand twin plus the touch, rhythm and capture modules. A working prototype, not a polished product, and the app only — its capture and asset tooling is not included. |
| [`app/`](app/) | The phone companion: the twin, session replay and the channel read-outs. One Expo codebase for iOS, Android and the browser, on the same synthetic feed or a real bridge. |
| [`bridge/`](bridge/) | The Python serial-to-WebSocket bridge that connects a real Teensy to any of the above, with a `--sim` mode that feeds synthetic joints. |
| [`watch/`](watch/) | The device screen's face assets. The face engine itself is firmware, in [`../firmware/takto_one/watch/`](../firmware/takto_one/watch/). |

The phone companion is in [`app/`](app/); it supersedes an earlier Android-only build, whose
source is not published. The sign-language stack is **not** in this release.

## Preview without hardware

The console needs nothing but a static file server. From the repository root:

```bash
python3 -m http.server 8096 --directory software/console/app
```

Open `http://localhost:8096/`. Point `--directory` at `software/web` instead to serve the
public front end, or at `software/ar` for the AR layer, which falls back to a desktop
preview when no WebXR device is present.

## Connect the Teensy

Create a Python environment and install the two bridge dependencies:

```bash
python3 -m venv .venv
.venv/bin/pip install -r software/bridge/requirements.txt
```

Run a bridge simulation:

```bash
SENSORYHAND_STATE_DIR=.takto-state .venv/bin/python software/bridge/teensy_bridge.py --sim
```

Or replace `--sim` with the detected Teensy port, for example:

```bash
SENSORYHAND_STATE_DIR=.takto-state .venv/bin/python software/bridge/teensy_bridge.py --port /dev/cu.usbmodemXXXX
```

Then open `http://localhost:8096/?ws=ws://localhost:8765/ws`.

The state-directory setting keeps local calibrations and captures inside an ignored repository folder. Do not commit recorded sessions or calibration files unless they have been reviewed for privacy.

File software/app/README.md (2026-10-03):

# TAKTO companion

A digital twin and instrument panel for TAKTO ONE, for iOS, Android and the
browser from one codebase.

<div align="center">
<a href="../../docs/media/app-live.gif">
<picture>
  <source media="(max-width: 767px), (pointer: coarse), (prefers-reduced-motion: reduce)" srcset="../../docs/media/app-live-still.png">
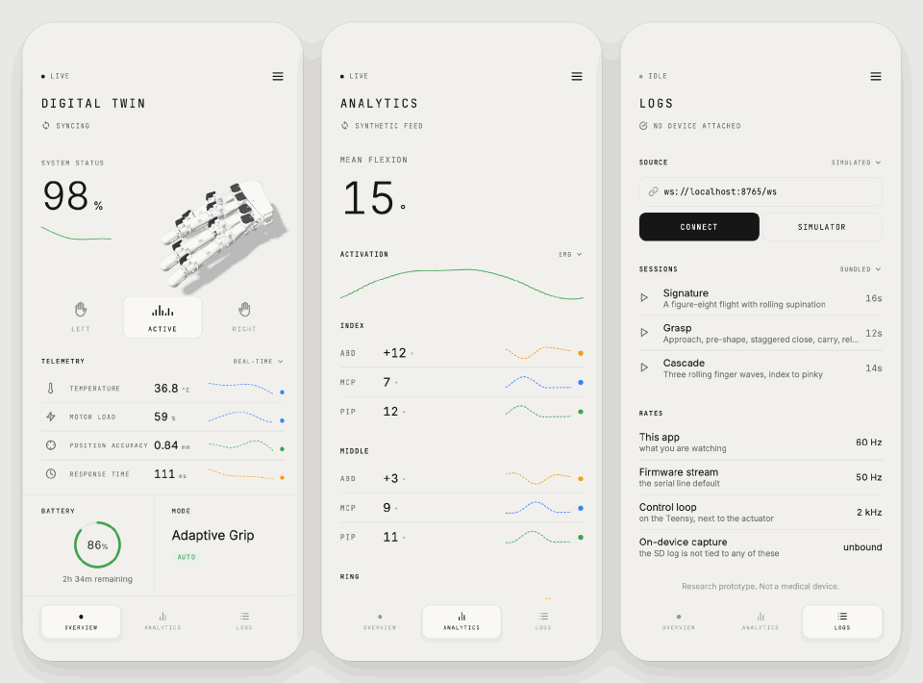
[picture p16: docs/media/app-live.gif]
Overview, Analytics and Logs running on one clock
  
</picture>
</a>
</div>

Three surfaces on one data path:

| | |
| --- | --- |
| **Overview** | The device at a glance: the twin lying on the page, the system health number and its trace, the hand picker, four housekeeping channels with live traces, the battery and the mode. |
| **Analytics** | The twelve joints and the activation channel as traces, finger by finger. |
| **Logs** | The source and its address, the bundled sessions to replay, and the four rates that are easy to confuse. |

Everything runs with **no hardware attached**. The app opens on a synthetic
feed; point it at a bridge from the Logs tab when you have a device.

## Run it

```bash
npm install
npx expo start
```

Then press `w` for the browser, `i` for an iOS simulator, or `a` for Android.
A native run builds through Expo in the usual way (`npx expo run:ios`,
`npx expo run:android`) and needs the corresponding platform toolchain.

To drive it from real hardware, start the bridge and give the app its address
on the Data screen:

```bash
SENSORYHAND_STATE_DIR=.takto-state python3 ../bridge/teensy_bridge.py --sim
```

`--sim` feeds synthetic joints; swap it for `--port /dev/cu.usbmodemXXXX` with
a Teensy attached. The default address is `ws://localhost:8765/ws`; from a
phone, use the machine's LAN address instead of localhost.

## What it is built on

- **The real CAD, at full resolution.** `assets/model/zero_hand_full.glb` is the
  repository's own export of the V7 assembly, 607k triangles, names and
  transforms untouched. It ships without normals, so the loader welds its
  vertices and computes smooth ones; `zero_hand.glb` (143k, web-decimated)
  stays beside it for low-memory devices, switched by one constant in
  `src/twin/loadHand.ts`. The rig binds to the GLB's own node names, because
  those names are the mechanism.
- **The shared mechanical model.** `src/data/kinematics.js` is carried
  byte-for-byte from `software/console`. Joint angles, the telescopic slides
  they demand, and the spool rotations that produce them all come from there.
  Nothing in the twin is tuned by eye.
- **The real take format.** The three bundled sessions are the repository's own
  samples from `software/bridge/samples/`, and a take recorded by the device
  drops in unchanged.
- **The real wire contract.** The bridge client reads the same `snap` frames
  the operator console reads.

## The look

A light instrument, built to a reference screen and checked against it
pixel for pixel at the reference's own 393 by 895 points:

- **The page** is one warm grey. There are no cards; the only surfaces are
  the three-tile pickers and the tab bar, and the only lines are hairlines.
- **Two typefaces.** JetBrains Mono, in tracked capitals, for every label.
  Inter for words and numerals, at weight 300 for the big ones.
- **The machine lies on the page** as in the product still: white, matte,
  seen from high and to the front, with a short soft shadow. It is the same
  articulated CAD as before, so it moves with the feed.
- **Three signal colours** belong to the traces and their dots: blue, green,
  amber. Green also marks the battery arc and the mode's AUTO tag. Nothing
  else is coloured.

Tokens are stated once in `src/ui/tokens.ts`; the shapes every screen is
built from are `src/ui/primitives.tsx` and `src/ui/Chrome.tsx`.

## Honest limits

- The twin renders **the mechanism**, not a person. Wrist articulation from the
  IMUs is not applied yet, and the thumb is sensing-only on the device.
- **Temperature, motor load, position accuracy, response time, battery and
  the health number are modelled by the synthetic feed**, not measured by the
  device. The bridge does not carry them yet; on a real link they show as a
  dash until the firmware reports them. The joints and the activation channel
  are the real contract.
- The reference still shows the tendon cables between hand and housing. The
  CAD export carries no cables, so the twin shows the gap.
- The screen on the forearm lights with activity. That is the glass lighting
  up, not a capture of the panel: the model carries no display content.
- The bundled takes are **choreographed and synthetic**, by their own README's
  admission. No hand wore the device to make them. The live synthetic feed is
  the same kind of thing: a 32 s choreography in `src/data/sim.ts` that rests
  open and spread, and departs from that pose into taps, a bloom, a wave and
  a grasp.
- The samples write anatomical values into the `{f}_mcp` column, which the
  device's wire contract uses for MCP **abduction**. This app maps columns the
  same way `software/web/src/views/replay.js` does, so replayed abduction can
  read past the mechanism's 16 degree limit. The transport says so and the
  twin clamps it.
- The full mesh is 10.9 MB in the bundle and 607k triangles on the GPU. It
  renders at 60 Hz on a laptop's software GL; on a low-end phone, flip
  `MODEL` in `src/twin/loadHand.ts` to `lite`.
- Verified on the **web** target, which is also what the capture tool renders
  and what every image on this page came from. The iOS and Android bundles
  export from the same source (`npx expo export --platform ios` and
  `--platform android`), but neither has been run on a device or a simulator
  here, so treat the native targets as compiling rather than as exercised.
  `expo-blur` on Android needs `experimentalBlurMethod` to blur at all, which
  is an open item for the first device run.

## Regenerating the media

The synthetic feed is a pure function of time and the app accepts `?t=`,
`?screen=` and `?take=`, so every captured frame is reproducible. See
[`tools/capture.mjs`](tools/capture.mjs) for the stills and the loop frames,
[`tools/compose.mjs`](tools/compose.mjs) for the docs composite, and
[`tools/gif.mjs`](tools/gif.mjs) for the loop.

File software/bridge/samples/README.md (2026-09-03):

# Sample takes

Three demonstration takes plus the Sim Lab environment mesh, so the session-replay
viewer has something to play on a fresh clone, before any hardware exists.

**These are choreographed, synthetic recordings.** No hand wore the device to make
them; every row is produced by the motion functions in [`generate.py`](generate.py),
which is the complete provenance: run it and you get these exact files. They use the
real take format, the real column layout, and the real device geometry, and they are
authored to move well for a camera, with the effort trace deliberately leading the
motion the way measured intent leads a real grasp.

| File | What it plays |
| --- | --- |
| `take_demo_cascade.json` | Three rolling finger waves, index to pinky, each pass fuller than the last (14 s) |
| `take_demo_grasp.json` | Approach, pre-shape, staggered close, carry, release (12 s) |
| `take_demo_signature.json` | A figure-eight flight with rolling supination; the hand breathes, then rests open (16 s) |
| `env_sim_lab.json` | The simulated lab room the takes reference (296 vertices, 148 triangles) |

## Replay them

Install the samples into the bridge's state store (its default store is the home
directory, with dot-prefixed names):

```bash
for f in software/bridge/samples/take_demo_*.json; do
  cp "$f" ~/.sensoryhand_takedata_$(basename "$f" .json).json
done
cp software/bridge/samples/env_sim_lab.json ~/.sensoryhand_env_env_0001.json
```

Start the bridge in simulation and serve the web app:

```bash
python3 software/bridge/teensy_bridge.py --sim &
python3 -m http.server 8096 --directory software/web
```

Open `http://localhost:8096/?ws=ws://localhost:8765/ws#/replay`. On a fresh store the
picker lists the samples. If you already have a take library, the picker shows only
your newest takes; load a sample directly from the browser console instead:

```js
const m = await import('/src/views/replay.js');
m.setReplayTake('take_demo_signature');
location.hash = '#/replay';
```

The takes reference `env_0001`, so the Sim Lab wireframe loads with them. Recording
your own takes writes the same format; see the capture surface in the web app.

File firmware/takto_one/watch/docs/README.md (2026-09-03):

# TAKTO watch face engine

Three switchable watch faces for the TAKTO ONE on-device screen, one engine,
one source of truth.

- **[FACE-ENGINE.md](FACE-ENGINE.md)** - the architecture, what each face is,
  and the honest gaps (read this one first).
- **[FRAME-BUDGET.md](FRAME-BUDGET.md)** - what the faces cost and what is
  still unmeasured.
- **[FLASH-RUNBOOK.md](FLASH-RUNBOOK.md)** - how to put it on the board and
  what to check.

**What the evidence is.** Every image of these faces in this repository is a
host render produced by the same C++ the Teensy runs, driven by a simulated
hand feed. The renders are not photographs of the panel. The on-device
frame-budget numbers, the firmware's own `T` report, have not been recorded in
this repository; step 6 of the flash runbook is how to take them.

## Where the pieces live

| what | where |
|---|---|
| the engine and the three faces | [`../`](../) (`watch_*.h`, `face_*.h`) |
| the sketch that runs it | [`../../takto_one.ino`](../../takto_one.ino), `screenService()` |
| the face catalog every surface reads | [`../../../../software/watch/catalog.json`](../../../../software/watch/catalog.json) |
| the bridge that serves the catalog | [`../../../../software/bridge/teensy_bridge.py`](../../../../software/bridge/teensy_bridge.py) |
| the console selector | [`../../../../software/console/app/src/views/operator.js`](../../../../software/console/app/src/views/operator.js), Tools drawer, "Watch face" |
| the browser mirrors of Ferro and Rams | [`../../../../software/web/src/watch_face_renderers.js`](../../../../software/web/src/watch_face_renderers.js) |

Not in this release: the host render and fidelity-test harness, the Ferro
design canon the second face was ported from, and a watch-face selector for
the phone companion (the app in `software/app/` does not carry one yet). The documents here describe them where the history matters.

## The rule that keeps it consistent

`catalog.json` is generated from the C++ face registry in `watch_engine.h`
and is the only face list the bridge and the console are allowed to read. If
you add a face or a colorway, update `catalog.json` in the same change or every
other surface goes stale. The bridge refuses to start without it.

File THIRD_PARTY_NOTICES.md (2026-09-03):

# Third-party notices

The browser console includes Three.js revision 160 and its `GLTFLoader` and `BufferGeometryUtils` add-ons. These files retain their upstream notices and are distributed under the MIT License:

Copyright © 2010-2023 Three.js Authors

Permission is hereby granted, free of charge, to any person obtaining a copy of this software and associated documentation files (the "Software"), to deal in the Software without restriction, including without limitation the rights to use, copy, modify, merge, publish, distribute, sublicense, and/or sell copies of the Software, and to permit persons to whom the Software is furnished to do so, subject to the following conditions:

The above copyright notice and this permission notice shall be included in all copies or substantial portions of the Software.

THE SOFTWARE IS PROVIDED "AS IS", WITHOUT WARRANTY OF ANY KIND, EXPRESS OR IMPLIED, INCLUDING BUT NOT LIMITED TO THE WARRANTIES OF MERCHANTABILITY, FITNESS FOR A PARTICULAR PURPOSE AND NONINFRINGEMENT. IN NO EVENT SHALL THE AUTHORS OR COPYRIGHT HOLDERS BE LIABLE FOR ANY CLAIM, DAMAGES OR OTHER LIABILITY, WHETHER IN AN ACTION OF CONTRACT, TORT OR OTHERWISE, ARISING FROM, OUT OF OR IN CONNECTION WITH THE SOFTWARE OR THE USE OR OTHER DEALINGS IN THE SOFTWARE.

## QR Code Generator for JavaScript

The public front end includes `software/web/vendor/qrcode-generator.js`, the QR Code Generator
for JavaScript by Kazuhiko Arase (<http://www.d-project.com/>), distributed under the MIT
License with its upstream notice retained:

Copyright © 2009 Kazuhiko Arase

Permission is hereby granted, free of charge, to any person obtaining a copy of this software and associated documentation files (the "Software"), to deal in the Software without restriction, including without limitation the rights to use, copy, modify, merge, publish, distribute, sublicense, and/or sell copies of the Software, and to permit persons to whom the Software is furnished to do so, subject to the following conditions:

The above copyright notice and this permission notice shall be included in all copies or substantial portions of the Software.

THE SOFTWARE IS PROVIDED "AS IS", WITHOUT WARRANTY OF ANY KIND, EXPRESS OR IMPLIED, INCLUDING BUT NOT LIMITED TO THE WARRANTIES OF MERCHANTABILITY, FITNESS FOR A PARTICULAR PURPOSE AND NONINFRINGEMENT. IN NO EVENT SHALL THE AUTHORS OR COPYRIGHT HOLDERS BE LIABLE FOR ANY CLAIM, DAMAGES OR OTHER LIABILITY, WHETHER IN AN ACTION OF CONTRACT, TORT OR OTHERWISE, ARISING FROM, OUT OF OR IN CONNECTION WITH THE SOFTWARE OR THE USE OR OTHER DEALINGS IN THE SOFTWARE.

"QR Code" is a registered trademark of DENSO WAVE INCORPORATED.

## ORCA hand, spool station geometry

The tendon spool station in this project derives from the **ORCA hand** by ORCA Dexterity, Inc.
(Soft Robotics Lab, ETH Zurich), published at
<https://github.com/orcahand/orcahand_hardware> and licensed under
[CC BY 4.0](https://creativecommons.org/licenses/by/4.0/).

- [`cad/stl/base_spool.stl`](cad/stl/base_spool.stl) is an **adaptation** of
  `orca_v1/ORCA_Spools/BaseSpool.stl`. It has been modified for TAKTO ONE.
- [`cad/third_party/orca/Ratchet.stl`](cad/third_party/orca/Ratchet.stl) is ORCA's
  `orca_v1/ORCA_Spools/Ratchet.stl`, redistributed **unmodified** and byte-identical. It stays
  under CC BY 4.0 and is **not** covered by this project's CERN-OHL-S-2.0 hardware licence. See
  [`cad/third_party/orca/README.md`](cad/third_party/orca/README.md).
- `cad/stl/spool_cover.stl` is TAKTO-authored and is **not** derived from ORCA's `SpoolCover.stl`.

Attribution, as CC BY 4.0 requires:

> ORCA hand, ORCA Dexterity, Inc., <https://www.orcahand.com>, licensed under CC BY 4.0.
> `base_spool` is modified from the original; the ratchet is used unmodified.

CC BY 4.0 permits an adaptation to be released under different terms, so the modified
`base_spool` is distributed under this project's CERN-OHL-S-2.0 hardware licence. The
attribution above is required regardless, and ORCA's own unmodified files remain CC BY 4.0.
The project is described in [arXiv:2504.04259](https://arxiv.org/abs/2504.04259).

Copyright © 2026 ORCA Dexterity, Inc.

The firmware expects Arduino libraries including Adafruit GFX. Those libraries are not vendored in this repository and remain subject to their own upstream licenses.

The film in `docs/media/` is scored with "The Theme" by Alex Jones and Xander Jones, obtained through the YouTube Audio Library. The track is used under that library's terms; it is not covered by this project's licences and is not relicensed by them.

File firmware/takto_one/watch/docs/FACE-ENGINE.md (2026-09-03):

# TAKTO watch face engine

Three complete watch faces for the on-device round screen (GC9A01, 240x240,
RGB565, Teensy 4.1), switchable at runtime from the console, with the choice
persisted on the device.

**What the evidence is:** every face is verified visually on a host build of
the same C++ the Teensy runs. Those renders are not photographs of the panel,
and the on-device frame-budget numbers have not been recorded in this
repository. `FLASH-RUNBOOK.md` is how to take them.

```
firmware/takto_one/watch/        the engine. Compiles unchanged for Teensy and for a host
  watch_state.h                    DeviceState, FaceState, Colorway, the WatchFace interface
  watch_gfx.h                      the RGB565 rasterizer + MiniCanvas1 text
  watch_fonts.h                    the three stock Adafruit GFX fonts
  watch_presentation.h             the presentation filters and paint cadence
  face_thesis.h                    FACE 1, a preservation port of the submitted UI
  face_ferro.h                     FACE 2, a port of the approved Ferro canon
  face_rams.h                      FACE 3, a new Braun/Rams instrument face
  watch_engine.h                   registry, selection, finger-amplitude law, carousel
software/watch/catalog.json      generated from the registry; the only face list anything reads
```

Not included in this release: the host render and fidelity-test harness
(`watch_render`, `fidelity_test`, the verbatim legacy copy and the mock feed),
the Ferro design canon, and the review renders. Where this document cites them
it is describing how the faces were verified, not files you will find here.

## The architecture

A face is a pure **consumer** of `DeviceState`. It reads the struct, paints a
240x240 framebuffer, and returns. It never reads a sensor, never touches a bus,
never blocks, and never triggers work of its own. The sketch owns everything
else and calls the engine in four steps:

1. fill a `DeviceState` from signals it already has;
2. `watch::engineUpdate(state, dt)` derives the per-finger amplitude envelope;
3. compare `watch::signature(state, carousel)` with the last one and return
   early if unchanged (the value-dirty rule the submitted firmware already
   used: identical signature means zero paint, zero tile scan, zero SPI);
4. `watch::engineRender(fb, state, carousel)`.

The panel push is untouched: the dirty-run DMA engine in `firmware_ui.h` still
ships at most one coalesced row band per loop pass.

### Dual target

The same headers compile for the Teensy and for a host binary that renders to
PNG. That is the verification backbone: every face, state and colorway is looked
at as an image before anything is flashed. Only the font tables come from
outside the repo (the stock `Adafruit_GFX_Library` the firmware already needs).

The sketch includes the engine directly from `firmware/takto_one/watch/`, so
there is exactly one copy of the face code and no install step.

## Face 1 - THESIS (preservation)

The on-wrist UI exactly as submitted. Every painter is moved verbatim from
`DeviceFirmware.ino`: same geometry, same constants, same quantized animation
phases. The only mechanical changes are that `millis()` became the engine clock
and the palette is indirected so a colorway can be selected.

A host fidelity test (not in this release) is the gate. It renders a
**verbatim copy** of the submitted painters and the engine's port side by side
for every original state at eight animation phases and compares them byte for
byte, plus it checks the text rasterizer against the raw font tables. Result at
the time of the port: **68 assertions, 0 failures, 0 differing pixels.**

If the port and the copy ever disagree, the **engine** is wrong; the submitted
painters are the reference.

Sapphire Depth is the original palette and the only canonical colorway. The two
extras are explicitly non-canonical recolors that change nothing but the palette
entries.

## Face 2 - FERRO (canon port)

A port of an approved design canon (a set of JavaScript canvas sketches, not
included here), not a redesign. Every parameter curve is transcribed from those
sketches with the numbers unchanged; the translation is JS canvas to RGB565
software rasterizer.

Per the canon's selection record: finger v5 Mass-lobe, boot v3 Fusion, idle v3 Breathe,
linked L1 Moon (the one explicit owner pick), standalone v3 Drift, teleop v3
Channel, recording recA Witness orbit, calib v3 Settle, stop v3 Freeze+invert,
fault v3 Fracture, battery v3 Thin/feed.

Boot is tagged **[B]** in the canon, so per the brief it uses its sketched
**[A] fallback**: no per-droplet gather memory, fade-in plus bloom ring-out with
bounded droplets. Everything else is [A] and implemented directly.

Feasibility follows FERRO-SPEC "Implementation readiness": a 140-step radius
LUT, 2-stop radial shading, at most 10 droplets and 7 feed dots, and a
precomputed crack tree. No solver, no allocation, no dynamic memory.

## Face 3 - RAMS (new design)

A precision instrument to Ferro's organism. Braun/Rams language: a strict grid,
near-monochrome with one accent, nothing decorative in motion.

**The layout is a documented system, not a set of chosen positions**, and the
header of `faces/face_rams.h` is its spec: a 4 px base unit with a fixed
spacing scale, exactly two text sizes (measured cap heights 35 px and 13 px),
a round-canvas rule (safe radius 106, composed centre-out, secondary readouts
on rings and arcs), and minimum stroke weights derived from what 32.5 mm
actually resolves at a wrist glance. Any state added later inherits it.

In short: the outer 270-degree scale ring plus a bold index bar is the primary
readout, the centre numeral sits on the exact geometric centre and only
confirms it, the EMG meter is the one cartesian instrument on a polar face, and
the gauge's own 90-degree dead sector at the bottom carries four per-finger
bars, ten charge segments, or a hatched warning band depending on state.

Three things were removed rather than compressed, which is the part of the
system that keeps it honest: twelve per-joint bars became four per-finger bars
(twelve bars in 13 mm mush into a grey block at arm's length), the "EMG"
caption went entirely (it cost a row and pushed the meter off the axis), and
the ring numerals went (the majors and the centre numeral already say it). The
accent is spent only on state signals, never on routine readings.

Verified on host renders at 240 px, at physical scale (141 px = 32.5 mm at
110 DPI), blurred for the squint test, and before/after per state.

Motion is information: the index breathes at rest and goes steady and accent
when engaged, teleop adds a second hollow index for commanded torque and fills
the sector between them, recording blinks a 1 Hz square, calibration grows the
captured span as an arc, a major fault adds a hatched warning band, and STOP
replaces the entire panel with a solid alarm field.

STOP uses a dedicated alarm red regardless of colorway. An e-stop that changes
appearance with a user preference is not an e-stop.

## Honest gaps, stated plainly

These are the places where the engine can render something the device cannot
currently produce. None of them are bugs; all of them would be lies if left
undocumented.

| Gap | The truth |
|---|---|
| `FS_BATTERY` | The board has **no fuel gauge**. The firmware never enters this state and always reports `battery = -1`. Both new faces implement it, and the harness exercises it, because the Ferro canon specifies it and a future board may have one. |
| `DeviceState.torque` | Measured, not commanded. The Teensy owns the motor bus, and the sketch fills this field with the largest measured motor current normalised by the software current cap (`I_CAP_MA`), or 0 whenever the bus is not taken or torque is off. It is a current-effort proxy, not a torque measurement at the finger; the faces label it as effort. |
| Thesis face, battery screen | The submitted firmware has **no battery screen**. The one here is an engine-era addition built from the thesis face's own vocabulary, and it is excluded from the pixel-fidelity gate because there is no original to be faithful to. |
| Ferro, `FS_SAVED` | The canon never explored a saved state. It is rendered as the canon's own documented recording exit (pinch-off, rejoin, completion ring-out), so no new vocabulary is invented, but it is canon-**derived**, not canon-selected. |
| Ferro, battery phases | The canon's battery entry is an 18 s demo **loop**. The device has real values, so the three phases are selected by `(battery, charging)` instead of by loop time. The curves inside each phase are unchanged. |
| `FS_STANDALONE` | New. The submitted firmware showed the searching-comet screen forever when the link went away; the shared state machine now distinguishes "never linked" (boot) from "was linked, link lost" (standalone), because the Ferro canon requires that distinction. The thesis face still renders it with its own vocabulary, and its **painters** remain pixel-identical, but this is a state-machine change, not a pure preservation. |
| Joint data when idle | Encoder channels are only read when something is already consuming them (streaming or recording). An idle, unlinked device reports `joints = -1` and the faces draw them as **absent** rather than inventing values. |
| Colorway `canonical: false` | Explored candidates or non-canonical recolors. Every surface must label them. A `note` containing `[panel-risk]` is a legibility warning from the design canon and must be shown, not hidden. |

## One deliberate change to a shared primitive

`blend565` (verbatim from the submitted firmware) computes
`(s*a + d*(255-a)) >> 8`, so at `a = 255` it returns one 565 level **below** the
source. On the thesis face that only ever touches thin anti-aliased edges and is
invisible. Ferro fills its whole body through the blend path and its darkest
gradient stops sit at 565 level 1, where losing a level rounds the mass to pure
black and the body vanishes into the field.

The alpha-aware primitives added for Ferro and Rams therefore write the source
directly at full coverage (`blendOver`). The verbatim primitives still call
`blend565` unchanged, which is why the thesis fidelity gate is still green.

## The finger-amplitude law

Shared by every face, derived once per tick by `watch::engineUpdate`:
`a_i = min(1, 4 * |dtheta_i/dt|)` over each finger's live channels, instant
attack, exponential decay with tau = 0.45 s. That is FERRO-SPEC's AMP rule, and
it is harmless to the faces that ignore it. Channels reading < 0 contribute
nothing, so a partially populated hand produces fewer deformations rather than
fake ones.

## Regenerating everything

The host harness that rendered the review sheets and regenerated the catalog is
not part of this release. What matters for a contributor is the invariant it
enforced:

`software/watch/catalog.json` mirrors the C++ registry in `watch_engine.h` and
is the **only** face list the bridge and the console are allowed to read. If
you add a face or a colorway, update `catalog.json` in the same change, or
every other surface goes stale. The bridge refuses to start without the file.

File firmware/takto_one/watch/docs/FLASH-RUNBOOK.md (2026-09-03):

# Flash runbook: the watch face engine on the physical screen

**What this establishes.** The face renders in this repository are host renders
of the same face code, not photographs of the panel, and the on-device
frame-budget numbers have not been recorded here. Walking this runbook on your
build is what turns the host evidence into device evidence.

Budget about 20 minutes. Nothing here needs the motors, the SEA runner, or a
host connection except where it says so.

---

## 0. Before you start

You need the Teensy connected by USB and `arduino-cli` with the Teensy board
package installed (the Arduino IDE bundles one; see
[`../../../README.md`](../../../README.md) for the compile line).

```bash
arduino-cli version
```

The sketch includes the face engine from its own `watch/` subfolder, so the
whole of `firmware/takto_one/` must be copied together if you move it.

## 1. Compile (should be identical to what is already verified)

```bash
cd <repo>/firmware/takto_one
arduino-cli compile --fqbn teensy:avr:teensy41 .
```

Expect roughly `FLASH: code:149484` and `RAM2: variables:250496`. A wildly
different RAM2 number means the vignette cache did not land in the second bank
and something in `face_thesis.h` was edited.

## 2. Flash

```bash
arduino-cli upload --fqbn teensy:avr:teensy41 -p /dev/cu.usbmodem* .
```

If the Teensy Loader does not pick it up, press the button on the board and
re-run. The Arduino IDE's own Upload button works just as well.

## 3. What you should see immediately

The device boots into whatever face was saved in EEPROM. On a board that has
never run this firmware, that is **the thesis face, sapphire** because the
magic byte will not match and it falls back to the canonical default.

With no host attached, the thesis face shows the **searching comet**: a sapphire
arc sweeping the bezel, the diamond of four sensor dots, and the breathing
centre. That is exactly what the submitted firmware showed, and it is the first
thing to confirm, because it is the preservation claim.

**If the screen is blank or shows garbage, stop.** Check `TFT_CS 10 / DC 9 /
RST 8` and the SPI wiring before blaming the engine.

## 4. Switch faces from the serial console

Open the Arduino Serial Monitor at 115200, or:

```bash
screen /dev/cu.usbmodem* 115200
```

Send `?` for the menu. The new command is `W,<face>,<colorway>`:

| command | expect |
|---|---|
| `W,0,0` | thesis, sapphire |
| `W,1,0` | ferro, electric blue |
| `W,2,0` | rams, signal yellow |
| `W,1,3` | ferro, deep red |
| `W,9,0` | **refused.** The echo ends in `,0` and the screen does not change |

Every one echoes `E,watch,<face>,<colorway>,<ok>`. `ok=1` means it applied it
AND wrote it to EEPROM.

**Power-cycle test:** set `W,2,0`, unplug, plug back in. It must come up on
Rams. That is the persistence claim, and it is the one most likely to be wrong
if the EEPROM address collides with something.

## 5. What each face should look like

Compare against `out/contact-all-states.png`, which is the host render of the
same code. Colours will not match perfectly (panel gamma, viewing angle), but
the geometry must.

**Thesis.** Sapphire on a soft dark vignette. No host: the searching comet.
Host connected and idle: the TAKTO five-bar mark near the top, a breathing azure
heart at centre, and a pentagon of five lamps (IMU, ENC, EMG, MOT, LNK). MOT
stays a hollow gold ring, not a fault, until the Teensy has taken the bus and
enabled torque (`M,t,1` then `M,e,1`); with motor power off that is the
expected state. A real drop-out turns a lamp coral and names it underneath.

**Ferro.** A dark ferrofluid pool on a near-black field with a lit rim. **This
is the one to scrutinise.** The canon puts the mass at #15181C on a #050607
field, which is a genuinely subtle 6 % luminance difference before the panel's
own gamma touches it. On the host render the body reads as a dark mass with a
bright rim. If on the panel it reads as an empty outline with nothing inside,
that is a real legibility finding and worth an issue: it is a property of the
approved canon, not a porting bug, and changing it is a design decision.

Move your instrumented finger and the mass should bulge toward that finger's
bearing along the top arc, with a small counter-lobe opposite. If nothing moves,
the encoders are not being read (see step 7).

**Rams.** Near-black, one yellow accent, a 270-degree tick scale with a bold
index bar riding it. Centre numeral, an EMG level bar, and twelve joint bars
along the bottom that are literally your hand's profile. At idle the index
breathes slowly; in an active state it stops breathing and goes yellow.

**STOP, on all three.** Thesis: a flashing coral ring and an octagon. Ferro: the
substance freezes and inverts to pale, with "S T O P" blinking. Rams: the entire
panel becomes a solid red field with black "STOP" and "MOTION DISABLED". If any
face's STOP is subtle, that is a bug worth reporting.

## 6. Measure the frame budget (this is the pending verification)

Send `T`. It prints the paint cost for the window since the last `T`:

```
# paint face=thesis/sapphire last=NNNNus max=NNNNus mean=NNNNus paints=N (N/s) samples=N (N/s) loop=N/s window=Nms tiles=N panel_runs=N panel_last=Nus panel_max=Nus slow=N cadence=100ms interact=80ms deferred=N pending=0 rot=N sync=1
```

Do this properly, because it is the only real number in the whole exercise:

1. `W,0,0`, then `T` twice about 10 s apart. Note `loop=N/s` and `mean`.
2. `W,1,0`, wait 10 s, `T` twice. Ferro animates continuously, but both
   `samples/s` and `paints/s` must stay at or below 10.0. `deferred` may rise
   when a full frame needs longer than 100 ms; that is intentional backpressure,
   not dropped sensor data.
3. `W,2,0`, same again.
4. Repeat all three with the host bridge connected and streaming, which is the
   loaded case.

Then hold each animated stage for 20 seconds and watch the whole circle. No
region may freeze while another updates, fast numerals must advance in stable
2 % steps rather than chatter, and capture time must change once per second.
Turn the crown quickly: the carousel may reach 12.5 Hz but must settle cleanly.
Finally enter SAFE: the state is checked every 20 ms and must appear without
waiting for the ordinary 100 ms cadence.

**The pass condition is that `samples/s <= 10.0` in normal faces, `pending`
returns to 0, no half-frame or flashing numeral appears, and `loop=N/s` does
not collapse when you switch from Thesis to Ferro or Rams.** If `deferred`
continues increasing while `pending` never returns to 0, record the `panel_max`
and `slow` numbers; that means the physical SPI path is not completing rather
than the animation running too quickly.

## 7. Switch faces from the console and the phone

With the bridge running against the real device:

```bash
cd <repo>
SENSORYHAND_STATE_DIR=.takto-state python3 software/bridge/teensy_bridge.py --port /dev/cu.usbmodem*
python3 -m http.server 8096 --directory software/console/app     # in another shell
```

Open `http://localhost:8096/?ws=ws://localhost:8765/ws#/operator`, expand
**Tools**, then **Watch face**.

- Pick a face and a colorway. The screen should change within a second.
- The caption under the swatches should now read that the **device confirmed
  it**. With no device attached it reads "held by the host", which is the
  honesty rule: until the Teensy echoes, nothing claims the screen changed.
- Any other client of the bridge shows the same state, since everything reads
  `snap.watch`.

## 8. Failure modes and what they mean

| symptom | cause |
|---|---|
| Blank screen, serial fine | SPI or panel wiring, not the engine |
| Comes up on the wrong face | EEPROM holds an older selection. Send the face you want; it saves |
| Always boots thesis/sapphire despite saving | The EEPROM write is failing or `WATCH_EE_ADDR` (64) collides with something. Check the `E,watch,...,1` echo is arriving |
| `E,watch,...,0` on a valid id | The index is out of range for the registry. Bring `software/watch/catalog.json` back in step with `watch_engine.h` so the host and the firmware agree |
| Console offers a face the device refuses | `catalog.json` is stale relative to the firmware. Same fix |
| Ferro looks like an empty outline | Expected-ish; see step 5. A legibility finding, not a port bug |
| Joint bars flat, Ferro does not deform | Encoders are only sampled while streaming or recording. Connect the bridge, or send `j` |
| Loop rate collapses on Ferro | The real frame-budget failure. Report the `T` numbers |

## 8b. The DOOM build

A separate firmware image, not in this release, links this same face engine and
hides a port of the 1993 DOOM behind a crown sequence on the round screen; the
remote-control page for it is still present in `software/web/src/views/doom.js`.
It needs soldered PSRAM and a FAT32 card holding the game data, and it is not
part of the face-engine verification. It is mentioned so the console's DOOM
route is not a mystery, not because there is anything here to flash.

## 9. When it works

Open an issue with the `T` numbers from step 6 for each face, loaded and
unloaded. Those are the measurements `FRAME-BUDGET.md` is waiting for, and a
photograph of each face on the panel is worth more than any render here.

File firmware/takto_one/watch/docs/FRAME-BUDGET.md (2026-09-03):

# Frame budget

A face that drops the sensor loop is a failure however good it looks. This is
what is known, what is measured, and what is still pending.

**Nothing here is a device measurement.** Every number below is from the host
target. The device numbers come from the firmware's own `T` report and have not
been recorded in this repository; `FLASH-RUNBOOK.md`, step 6, is how to take
them.

## What the engine costs

`watch_render --profile` times one paint. `watch_render --duty` is the number
that actually matters: it walks simulated time, counts the paints the
**value-dirty signature** asks for, and reports milliseconds of paint per
second of wall clock. The physical firmware now applies a stricter 130 ms
presentation gate after this host-side characterization.

Per-paint cost is unremarkable, 0.03 to 0.54 ms across all three faces on the
host. The interesting difference is frequency: the thesis face is static between
quantized animation steps and paints 2.3 times a second at idle, while Ferro
breathes continuously and paints 21.5 times a second.

That makes per-state ratios useless as a safety signal (any animated face is
"hundreds of times" a nearly static one). The ceiling that matters is the
busiest thing the submitted firmware **already sustains on the hardware**, which
is its own teleoperation screen at 20.6 paints/s.

| face | worst sustained duty (host) | vs the thesis face's worst |
|---|---|---|
| thesis | 6.85 ms/s (teleop) | 1.00x |
| rams | 7.99 ms/s (calib) | **1.17x** |
| ferro | 9.67 ms/s (fault) | **1.41x** |

So in its heaviest state each new face asks for roughly 1.2 to 1.4 times the
paint work the device is already known to do in its own heaviest state. That is
a ratio between two measurements taken the same way on the same machine, which
is the part that transfers; the absolute milliseconds do not.

**Always read the ratio, never the milliseconds.** The absolute figures move by
up to 75 % with whatever else the host is doing: the same unchanged Ferro code
measured 10.37, 16.88 and 9.67 ms/s in three sessions. The ratio held at
1.41-1.44x across all of them, which is what makes it usable. Any comparison
must therefore come from a single `--duty` run, and a run taken while a build
is going is worthless.

### Rams after the spacing-system pass (2026-07-30)

The Rams re-lay was checked state by state against its own previous layout,
each side normalised to the thesis face's worst state in the same run. Every
state got cheaper and none regressed:

| state | before | after | | state | before | after |
|---|---|---|---|---|---|---|
| boot | 1.18x | 0.99x | | saved | 1.12x | 0.91x |
| idle | 1.13x | 0.94x | | stop | 0.39x | 0.39x |
| linked | 1.10x | 0.90x | | fault | 1.11x | 0.93x |
| standalone | 1.02x | 0.75x | | battery | 1.08x | 0.87x |
| teleop | 1.34x | 1.15x | | **worst** | **1.36x** | **1.17x** |
| recording | 1.13x | 0.91x | | calib | 1.36x | 1.17x |

Fewer, larger elements are cheaper to rasterize than many small ones, which is
why a legibility pass paid for itself. One thing did regress on the first cut:
the major-fault hatch bounded its scan by the full circle instead of the wedge,
which pushed fault from 1.11x to 1.39x. Bounding the wedge properly brought it
to 0.93x. Ferro was untouched and reproduced its 1.41x, which is the control
that says the harness itself did not drift.

## Why the ratio may not transfer exactly

Say so rather than pretend otherwise:

- The host has a much faster FPU and much larger caches than a 600 MHz
  Cortex-M7. The two faces are not merely scaled-up versions of the thesis
  face, they lean on different maths.
- Ferro's body pass calls `atan2f` and `sqrtf` **per pixel** inside the mass
  bounding box. The thesis face's primitives are `sqrtf`-heavy but call no
  inverse trig. If `atan2f` is relatively more expensive on the M7's libm than
  on the host's, Ferro's ratio gets worse.
- Rams is dominated by rectangle fills and short anti-aliased segments, which
  are the cheapest possible operations on either target, so its ratio should
  transfer better than Ferro's.

The bound is therefore a good planning number and a bad guarantee. Measure it.

## What protects the sensing loop regardless

- **Normal presentation is capped at 130 ms** (7.7 Hz) in `screenService()`;
  the crown carousel is 104 ms (9.6 Hz). State and safety are still inspected
  every 20 ms (50 Hz), and a state/face/safety discontinuity paints immediately.
- **A new framebuffer is never built while the previous one is still being
  shipped.** If the panel is busy when an animation sample becomes due, that
  visual sample is skipped/deferred. Sensor and control samples are not.
- **Readouts are presentation-filtered:** joints use a 300 ms low-pass, EMG and
  roll 350 ms, torque 250 ms, and calibration 200 ms; normalized values are
  displayed in 2 % steps and roll in 2 degree steps. The underlying telemetry
  and control values are unchanged.
- **The value-dirty signature** means a face that is not changing costs zero
  paint, zero tile scan and zero SPI. Ferro's STOP state paints 0.5 times a
  second because the substance is frozen.
- **The panel push is bounded and coherent**: `firmware_ui.h` ships at most one
  synchronous coalesced 64 x 16 px run per loop pass, commits its shadow only
  after the write returns, and now finishes that frame before the next buffer
  is built.
- **Faces never do I/O.** They cannot read a sensor or touch a bus even by
  accident; they only receive a filled `DeviceState`.
- **Encoder reads went down, not up.** `emitStream()` and `recWrite()` used to
  read every channel over I2C independently, so a frame that was both recording
  and streaming read each channel twice. They now share one pass, and it is only
  taken when something is consuming it.

## Memory

Measured from the two compiles, same board, same toolchain:

| | before (submitted) | after (three faces) |
|---|---|---|
| FLASH code | 103,596 | 149,484 |
| RAM1 variables | 16,512 | 26,784 |
| RAM2 variables | 250,496 | 250,496 |
| free for local variables | 376,704 | 333,664 |

The three faces cost about 46 kB of flash out of roughly 8 MB free. RAM2 is
byte-identical because the 115 kB vignette cache stayed in the second bank
exactly where the submitted firmware put it.

## Getting the real numbers

The firmware measures itself. Send `T` over the serial console (115200) and it
prints, for the window since the last `T`:

```
# paint face=ferro/electric-blue last=NNNNus max=NNNNus mean=NNNNus paints=N (N/s) samples=N (N/s) loop=N/s window=Nms tiles=N panel_runs=N panel_last=Nus panel_max=Nus slow=N cadence=100ms interact=80ms deferred=N pending=0 rot=N sync=1
```

`loop=N/s` is the one to watch. Compare it against the same reading on the
thesis face: if the loop pass rate holds, the sensing duty is intact. The
procedure is step 6 of the flash runbook.

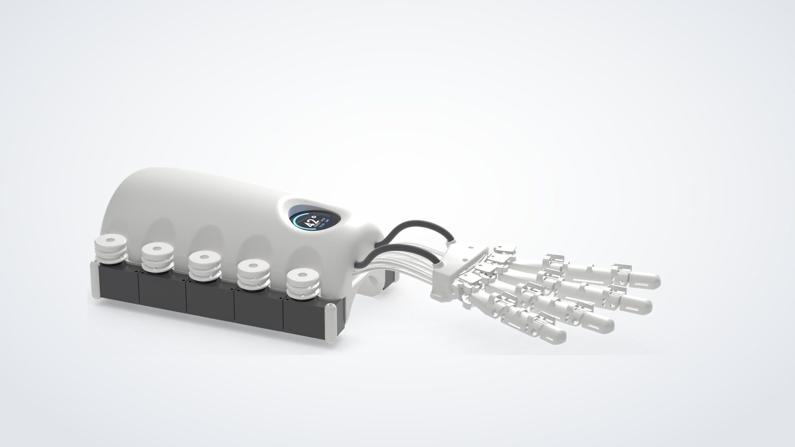
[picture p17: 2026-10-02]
software/web/assets/px/film-poster.jpg

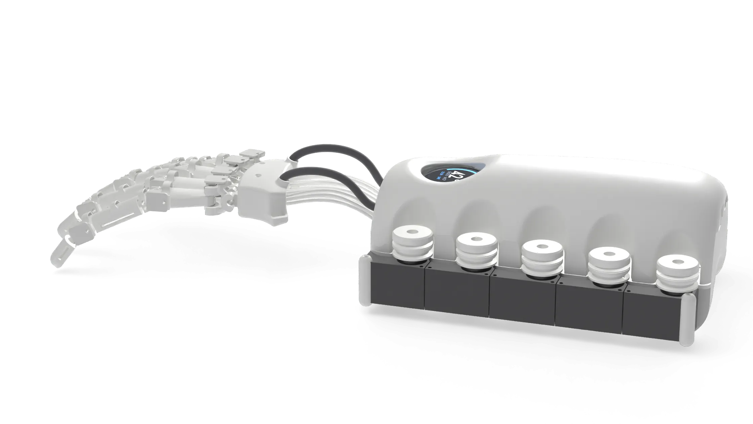
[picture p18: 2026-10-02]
software/web/assets/px/turn3/f03.webp

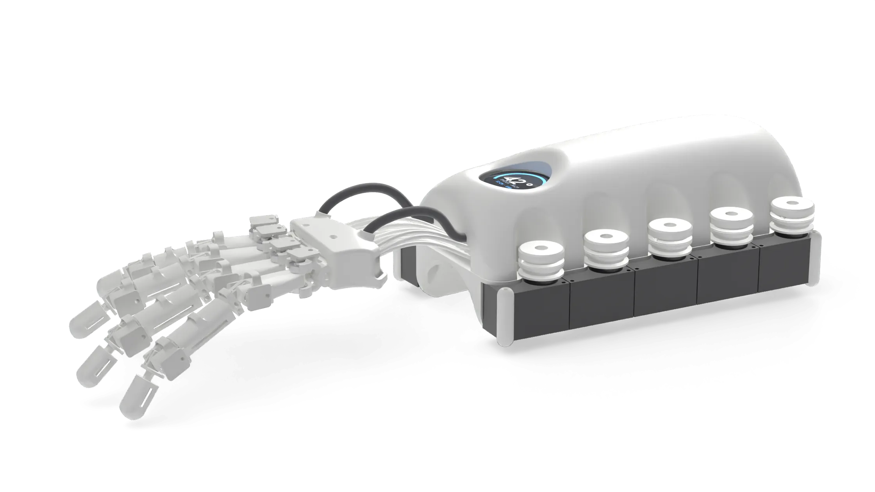
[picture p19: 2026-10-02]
software/web/assets/px/turn3/f66.webp

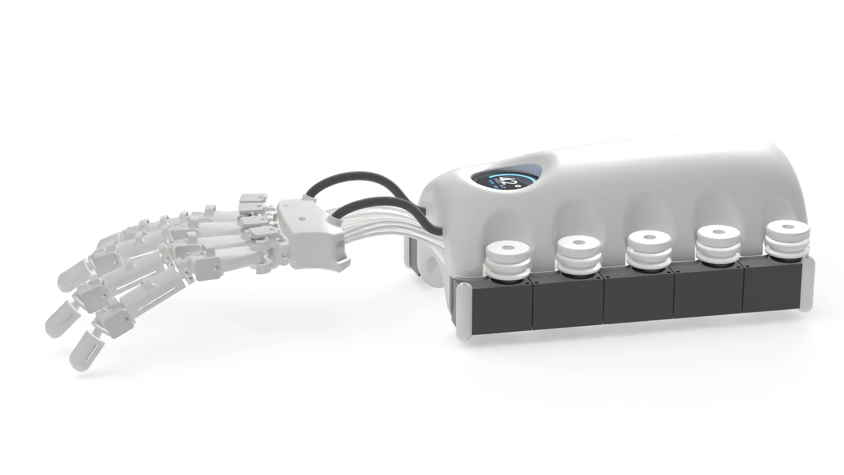
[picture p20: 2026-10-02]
software/web/assets/px/turn3/f69.webp

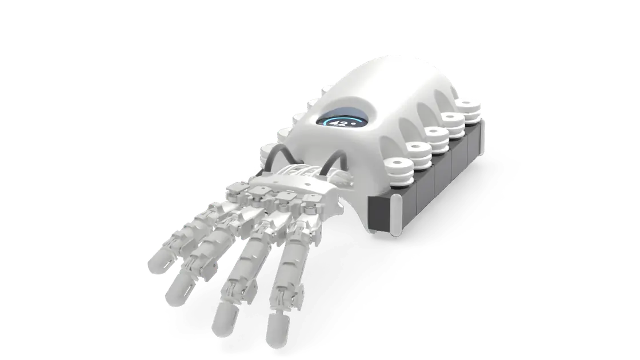
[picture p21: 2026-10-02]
software/web/assets/px/turn2/f58.webp

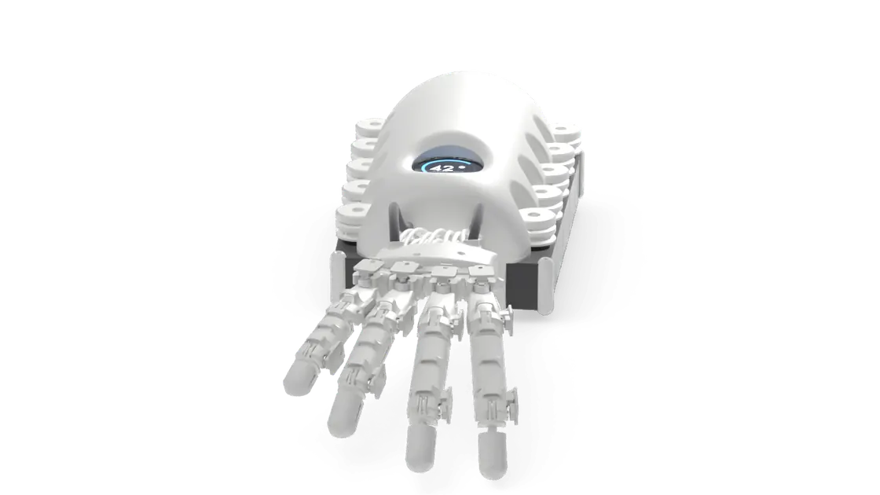
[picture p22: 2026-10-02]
software/web/assets/px/turn2/f55.webp

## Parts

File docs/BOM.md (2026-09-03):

# Bill of materials

**Scope: the four-finger configuration — eight motors, twelve instrumented joints.** That is
what the device controls today, and it is what the published CAD, boards and firmware were
dimensioned around.

<div align="center">
  <picture>
    <source media="(prefers-color-scheme: dark)" srcset="media/bom-cost-dark.svg">
    Parts cost by group: actuation EUR 1040 of a EUR 1222.25 total, then print stock 50.00, motion sensing 44.38, control 43.97, joint sensing 26.40, transmission 17.50
  </picture>
</div>

Two things this total is not. The forearm carries **ten** spool/tensioner bays, not eight: the
two spare bays are deliberate headroom for a thumb pair, and the firmware already addresses
fourteen encoder channels of which twelve are populated. Nobody has built that thumb — its
linkage, its tendon routing and its kinematics are all open, and it is named as an invitation
in the top-level README. And the shipped firmware is configured for **two** motors
(`N_MOTOR = 2` in `firmware/takto_one/takto_one.ino`), one antagonist pair on one finger, which
is the bench setup rather than a full build. Buy against the configuration you intend to build.

Quantities come from primary sources, not from an earlier parts list: the firmware pin map and
constants, the two KiCad projects and their manufacturing BOMs, and the export manifest in
[`../cad/README.md`](../cad/README.md). A machine-readable copy of every line below is in
[`bom.csv`](bom.csv).

> **Prices are indicative, not a quotation.** They are carried from the project's own 2026
> purchasing at the suppliers named, are **ex VAT and ex shipping** unless a line says
> otherwise, and were correct to the best of the author's records in **2026**. Semiconductor
> and motor pricing moves — re-quote every line before ordering. Lines marked `—` were bought
> as part of a larger order, salvaged, or not separately recorded; they are real requirements
> with no price the author can honestly publish.

---

## Actuation

| Item | Part number | Supplier | Qty | Unit (EUR) |
| --- | --- | --- | ---: | ---: |
| Dynamixel servo | XC330-M181-T | Robotis / mybotshop.de | 8 | 130.00 |

Two per long finger, an antagonist pair on one spool. The firmware names this model both in its
baud ceiling and in its model check, so a different XC330 variant will not pass `M,t,1`.

A **U2D2 interface set** (EUR 103.95) appears in older costings and is **not required**. The
Teensy owns the bus through the 74HC241; a U2D2 is a development and diagnostic convenience
only, and must be physically disconnected before the firmware will take the bus — it enforces
single-master.

## Sensing

| Item | Part number | Supplier | Qty | Unit (EUR) |
| --- | --- | --- | ---: | ---: |
| AS5600 magnetic encoder IC | AS5600-ASOM · LCSC `C79815` | AMS / JLCPCB | 12 | — |
| Diametric magnet, N35 6 × 2.5 mm | — | generic | 12 | 2.20 |
| 100 nF 0805 capacitor | LCSC `C49678` | JLCPCB | 24 | — |
| BNO085 IMU breakout | — | generic / Amazon.de | 2 | 22.19 |
| Surface EMG sensor, envelope out | MyoWare 2.0 | SparkFun / generic | 1 | — |

One encoder and one magnet per instrumented joint, three per long finger; two capacitors per
encoder board. The ICs are supplied and placed as part of the JLCPCB assembly order below.

The firmware addresses **14** encoder channels (`N_CHANNELS = 14`, muxes at `0x70` and `0x71`),
of which twelve are populated here — channels 12 and 13 are wired-through spares for a thumb.

Two IMUs are fitted, at dorsal hand (`0x4A`, `Wire1`) and forearm (`0x4B`, `Wire2`). The
firmware and the wiring carry a third position at the thumb tip (`0x4B`, `Wire1`); the BNO085
has only two addresses, so the thumb would share the hand bus at the second address. It is not
populated here and is not priced above — add one BNO085 (**+EUR 22.19**) to fit it. The
unpopulated channel reports MISSING in the `s` bus scan and streams a live flag of zero. EMG is optional: its envelope goes to pin 14 (A0), and the firmware reports the
sensor as absent and runs without it. The MyoWare 2.0 is a three-lead sensor: two electrodes
along the muscle belly and one reference on quiet tissue, taking standard disposable Ag/AgCl
gel electrodes.

## Control and interface

| Item | Part number | Supplier | Qty | Unit (EUR) |
| --- | --- | --- | ---: | ---: |
| Teensy 4.1 | TEENSY41 | PJRC | 1 | 31.20 |
| Round display, 1.28 in 240 × 240 | GC9A01A | generic / Amazon.de | 1 | 12.50 |
| Octal buffer / line driver | SN74HC241N | TI / Reichelt | 1 | 0.27 |
| microSD card | — | generic | 1 | — |
| Potentiometer, the crown | — | generic | 1 | — |
| Tactile button | — | generic | 1 | — |
| Piezo buzzer | — | generic | 1 | — |
| Motor supply and wiring | — | — | 1 | — |

The Teensy runs at 600 MHz, owns the motor bus and runs the control law; its built-in SDIO
socket is the capture target, so size the card for the recording length you want. The display
is on SPI0 (CS 10 / DC 9 / RST 8) and is painted by the firmware's own rasterizer. Crown on pin
27 (A13), presence-checked so an unwired pin cannot fabricate assist authority; button on pin 5;
piezo on pin 2.

The **74HC241** is the half-duplex Dynamixel interface on `Serial1`, direction on pin 7
(HIGH = transmit). It is **central to the current architecture** — earlier documentation calling
it a superseded part is wrong. It is not on the published palm-carrier Gerbers, so wire it
separately and verify the truth table, voltage domains, common ground and receive-default state
on the bench. Keep actuator power independently removable; see the safety note in the top-level
README.

## Custom boards

| Item | Source | Qty |
| --- | --- | ---: |
| Encoder board, AS5600 | [`../electronics/encoder_board/`](../electronics/encoder_board/) | 12 |
| Palm carrier / multiplexer board | [`../electronics/palm_carrier/`](../electronics/palm_carrier/) | 1 |
| TCA9548A I²C multiplexer | LCSC `C130026` | 2 |
| Palm carrier passives | LCSC `C15850`, `C49678`, `C17673`, `C17414` | 1 set |

Both boards were fabricated and assembled in a **single JLCPCB order on 2026-06-17: USD 170.73
delivered** — merchandise USD 127.83, shipping USD 15.64, customs and duties USD 27.26. Within
that order the palm carrier PCBA was USD 50.59 for five pieces. Treat these as what one order
actually cost, not as a per-unit price. The muxes sit on the palm carrier: `0x70` serves
channels 0–7, `0x71` serves channels 8–13. Passives are 1 × 10 µF, 2 × 100 nF, 2 × 4.7 k and
2 × 10 k; the full list is in the board's manufacturing BOM.

> **Erratum, palm carrier channels 8–13.** On the second multiplexer (`U2`) the `SDA`/`SCL` net
> labels are transposed on all six used channels. Wire your sensor's `SCL` to the pad marked
> `SDA` and its `SDA` to the pad marked `SCL`. `U1` (channels 0–7) is correct as labelled.
> Detail in [`README.md`](README.md).

## Transmission and mechanical hardware

| Item | Part number | Supplier | Qty | Unit (EUR) |
| --- | --- | --- | ---: | ---: |
| Braided UHMWPE tendon, 0.30 mm | J-Braid X8 | Daiwa | 1 spool | 17.50 |
| PTFE conduit | — | generic | — | — |
| Ratchet, printed | [`../cad/third_party/orca/`](../cad/third_party/orca/) | ORCA hand · CC BY 4.0 | 10 | — |
| Elastic tendon element | — | generic | 8 | — |
| Fasteners and pins | — | generic | — | — |

An antagonist cable pair runs on one 5 mm spool per joint, so flexion and extension come from
the same motor with no backlash at reversal. Conduit length depends on your forearm-to-hand run.
The ratchet, one per spool station, is **third-party geometry from the ORCA hand project**,
redistributed unmodified under CC BY 4.0 and printed like any other part; it is not covered by
this project's CERN-OHL-S-2.0 licence. See [`../THIRD_PARTY_NOTICES.md`](../THIRD_PARTY_NOTICES.md).
The elastic elements are what make the actuation series-elastic — a simple implementation of
the idea, elastic tendons and ratchet spools, not an advanced SEA design — and the transmission
has been run on the bench both with and without them in series. Fasteners are not
enumerated in this release; select and verify them against the STEP files.

## Printed parts

| Item | Supplier | Qty | Unit (EUR) |
| --- | --- | ---: | ---: |
| PETG filament | generic | 1 kg | 20.00 |
| TPU filament | generic | 1 kg | 30.00 |
| PLA filament | generic | 1 kg | — |

**61 TAKTO-authored printed occurrences across 24 unique components**, plus the **10
ORCA-derived ratchets** above: 71 printed parts in a full build. The TAKTO parts are all in
[`../cad/stl/`](../cad/stl/) with
editable solids in [`../cad/step/`](../cad/step/) and the per-part manifest, with Fusion cloud
versions, in [`../cad/README.md`](../cad/README.md). Ten of those occurrences are `BaseSpool` and
ten are `SpoolCover` — the ten tensioner bays the forearm provides, of which eight are used here.
PETG is structural and TPU is the compliant skin interface; the as-built prototype mixes PETG and
PLA, so any claim that it is entirely PETG is wrong.

Two links per finger are engineered for metal additive manufacturing in AlSi10Mg or 316L. That
path was studied in CAD and linear-static FEA; **no metal parts were fabricated**, and no metal
build is claimed here. Machine time for in-house LPBF is not costed.

---

## Cost summary

| Group | EUR |
| --- | ---: |
| Actuation — 8 × XC330-M181-T | 1040.00 |
| Motion sensing — 2 × BNO085 | 44.38 |
| Print stock — PETG + TPU | 50.00 |
| Control — Teensy 4.1, GC9A01A, SN74HC241N | 43.97 |
| Joint sensing — 12 magnets | 26.40 |
| Transmission — tendon | 17.50 |
| **Priced subtotal** | **1222.25** |

Both custom boards came to a further **USD 170.73** as one delivered order. These lines carry no
published price and are not in the subtotal: EMG sensor, microSD, crown pot, button, piezo, motor
supply and wiring, PTFE conduit, elastic elements, fasteners, PLA stock.

**This supersedes the EUR 1,599.84 figure** that earlier project material quoted. That number was
an earlier costing of the same four-finger design, and it differs for two reasons: it included a
U2D2 set at EUR 103.95, which the current motor architecture does not need, and it attributed the
whole JLCPCB order to a single PCB line at EUR 155.21 rather than recording it as one order
covering both boards. The project website carries the same figure as this page, so the two agree;
if you change one, change the other.

**The eight motors are most of the cost, and that is the honest headline.** Reducing the motor
count through underactuation is the single change that would most widen who can build this, and
it is named as an open invitation in the top-level README.

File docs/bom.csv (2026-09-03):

group | item | part_number | supplier | qty | unit_eur | in_total | notes
Actuation | Dynamixel servo | XC330-M181-T | Robotis / mybotshop.de | 8 | 130.00 | yes | Two per long finger; antagonist pair on one spool
Actuation | U2D2 interface set | U2D2 SET | Robotis / mybotshop.de | 0 | 103.95 | no | Not required: the Teensy owns the bus through the 74HC241. Development and diagnostics only; must be disconnected before the firmware will take the bus
Joint sensing | AS5600 magnetic encoder IC | AS5600-ASOM / LCSC C79815 | AMS / JLCPCB | 12 |  | yes | One per instrumented joint; placed as part of the JLCPCB assembly order
Joint sensing | Diametric magnet N35 6x2.5 mm |  | generic | 12 | 2.20 | yes | One per encoder, on the rotating side of each joint
Joint sensing | Capacitor 100nF 0805 | LCSC C49678 | JLCPCB | 24 |  | yes | Two per encoder board
Motion sensing | BNO085 IMU breakout |  | generic / Amazon.de | 2 | 22.19 | yes | Dorsal hand 0x4A Wire1; forearm 0x4B Wire2. Third position (thumb tip 0x4B Wire1) wired but not populated
Effort sensing | Surface EMG sensor with envelope output | MyoWare | generic | 1 |  | yes | Teensy pin 14 (A0). Optional: firmware reports EMG absent and runs without it
Control | Teensy 4.1 | TEENSY41 | PJRC | 1 | 31.20 | yes | 600 MHz; owns the motor bus and runs the control law; built-in SDIO socket is the capture target
Control | Octal buffer / line driver | SN74HC241N | Texas Instruments / Reichelt | 1 | 0.27 | yes | Half-duplex Dynamixel interface on Serial1, direction pin 7 HIGH = transmit. Not on the published Gerbers; wire separately
Control | Round display 1.28 in 240x240 | GC9A01A | generic / Amazon.de | 1 | 12.50 | yes | SPI0, CS 10 / DC 9 / RST 8
Control | microSD card |  | generic | 1 |  | yes | Teensy 4.1 built-in SDIO socket; one row per frame
Control | Potentiometer (the crown) |  | generic | 1 |  | yes | Pin 27 (A13); presence-checked
Control | Tactile button |  | generic | 1 |  | yes | Pin 5
Control | Piezo buzzer |  | generic | 1 |  | yes | Pin 2
Control | Motor supply and wiring |  |  | 1 |  | yes | Sized for eight XC330 servos; keep actuator power independently removable
Custom PCB | Encoder board (AS5600) | electronics/encoder_board | JLCPCB | 12 |  | yes | One per joint; KiCad source plus Gerbers, placement and BOM in the repo
Custom PCB | Palm carrier / multiplexer board | Zero_Palm_V1 | JLCPCB | 1 |  | yes | Erratum: U2 channels 8-13 have SDA/SCL net labels transposed; swap the two signal wires relative to the label
Custom PCB | TCA9548A I2C multiplexer | LCSC C130026 | JLCPCB | 2 |  | yes | 0x70 for channels 0-7; 0x71 for channels 8-13
Custom PCB | Palm carrier passives | LCSC C15850, C49678, C17673, C17414 | JLCPCB | 1 |  | yes | 1x 10uF, 2x 100nF, 2x 4.7k, 2x 10k; full list in the board manufacturing BOM
Transmission | Braided UHMWPE tendon 0.30 mm | J-Braid X8 | Daiwa | 1 | 17.50 | yes | Antagonist cable pair on one 5 mm spool per joint
Transmission | PTFE conduit |  | generic |  |  | yes | Length depends on the forearm-to-hand run
Transmission | Ratchet (printed; ORCA hand CC BY 4.0) | cad/third_party/orca/Ratchet.stl | ORCA hand project | 10 |  | yes | One per spool station; third-party geometry, not under CERN-OHL-S; see THIRD_PARTY_NOTICES.md
Transmission | Elastic tendon element |  | generic | 8 |  | yes | Makes the actuation series-elastic; simple implementation, not an advanced SEA design
Mechanical | Fasteners and pins |  | generic |  |  | yes | Not enumerated in this release; select and verify against the STEP files
Printed parts | PETG filament |  | generic | 1 | 20.00 | yes | Structural parts; 1 kg
Printed parts | PLA filament |  | generic | 1 |  | yes | The as-built prototype mixes PETG and PLA; 1 kg
Printed parts | TPU filament |  | generic | 1 | 30.00 | yes | Compliant skin-interface parts; 1 kg

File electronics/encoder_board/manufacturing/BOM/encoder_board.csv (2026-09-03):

Reference | Qty | Value | DNP | Exclude from BOM | Exclude from Board | Footprint | Datasheet | LCSC | Manufacturer | Package
C1,C2 | 2 | 100nF |  |  |  | Capacitor_SMD:C_0805_2012Metric |  | C49678
U1 | 1 | AS5600-ASOM |  |  |  | Package_SO:SOIC-8_3.9x4.9mm_P1.27mm | https://ams-osram.com/products/sensors/position-sensors/ams-as5600-position-sensor | C79815 | AMS | SOIC-8

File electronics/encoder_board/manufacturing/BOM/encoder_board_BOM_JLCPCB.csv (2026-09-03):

Comment | Designator | Footprint | LCSC Part #
100nF | C1,C2 | C_0805_2012Metric | C49678
AS5600-ASOM | U1 | SOIC-8_3.9x4.9mm_P1.27mm | C79815

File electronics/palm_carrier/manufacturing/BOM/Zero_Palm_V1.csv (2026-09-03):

Reference | Qty | Value | DNP | Exclude from BOM | Exclude from Board | Footprint | Datasheet | LCSC
C3 | 1 | 10uF |  |  |  | Capacitor_SMD:C_0805_2012Metric |  | C15850
C4,C5 | 2 | 100nF |  |  |  | Capacitor_SMD:C_0805_2012Metric |  | C49678
R3,R4 | 2 | 4.7k |  |  |  | Resistor_SMD:R_0805_2012Metric |  | C17673
R5,R6 | 2 | 10k |  |  |  | Resistor_SMD:R_0805_2012Metric |  | C17414
U1,U2 | 2 | TCA9548APWR |  |  |  | Package_SO:TSSOP-24_4.4x7.8mm_P0.65mm | http://www.ti.com/lit/ds/symlink/tca9548a.pdf | C130026

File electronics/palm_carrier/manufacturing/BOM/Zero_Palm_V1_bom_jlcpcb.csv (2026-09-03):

Comment | Designator | Footprint | LCSC Part #
10uF | C3 | Capacitor_SMD:C_0805_2012Metric | C15850
100nF | C4,C5 | Capacitor_SMD:C_0805_2012Metric | C49678
4.7k | R3,R4 | Resistor_SMD:R_0805_2012Metric | C17673
10k | R5,R6 | Resistor_SMD:R_0805_2012Metric | C17414
TCA9548APWR | U1,U2 | Package_SO:TSSOP-24_4.4x7.8mm_P0.65mm | C130026

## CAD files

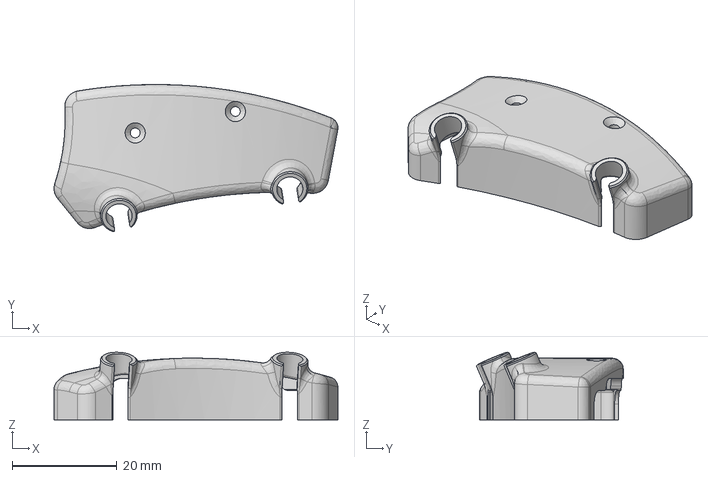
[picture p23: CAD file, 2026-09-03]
cad/step/zero_palm_cap_v3.step
54.2 x 28.0 x 12.9 mm

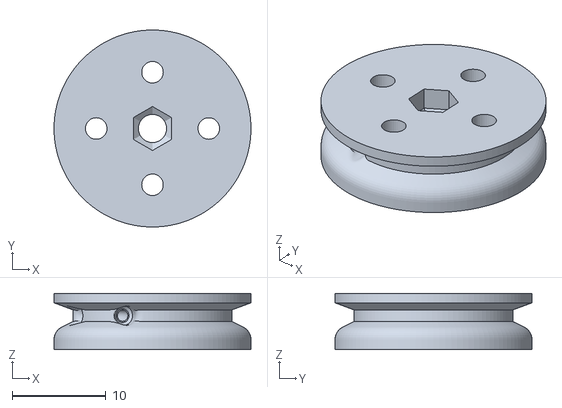
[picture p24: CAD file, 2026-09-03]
cad/stl/base_spool.stl
21.0 x 21.0 x 5.99

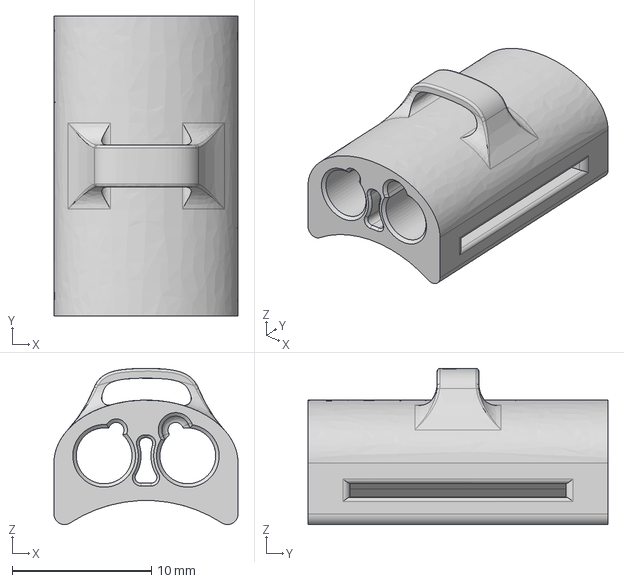
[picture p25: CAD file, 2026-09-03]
cad/step/zero_finger4_mcp_center_v3.step
13.2 x 21.5 x 11.2 mm

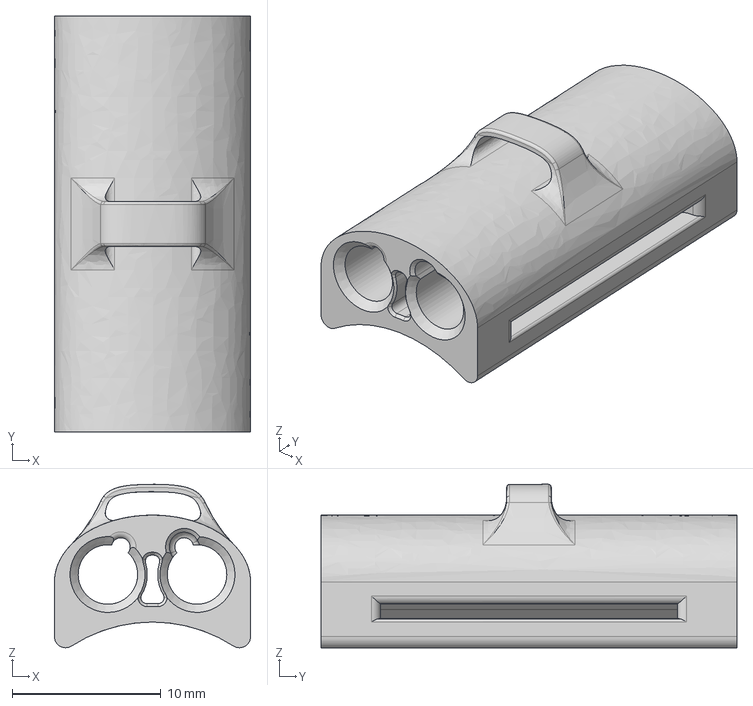
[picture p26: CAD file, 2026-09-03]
cad/step/zero_finger2_mcp_center_v3.step
13.2 x 28.0 x 11.0 mm

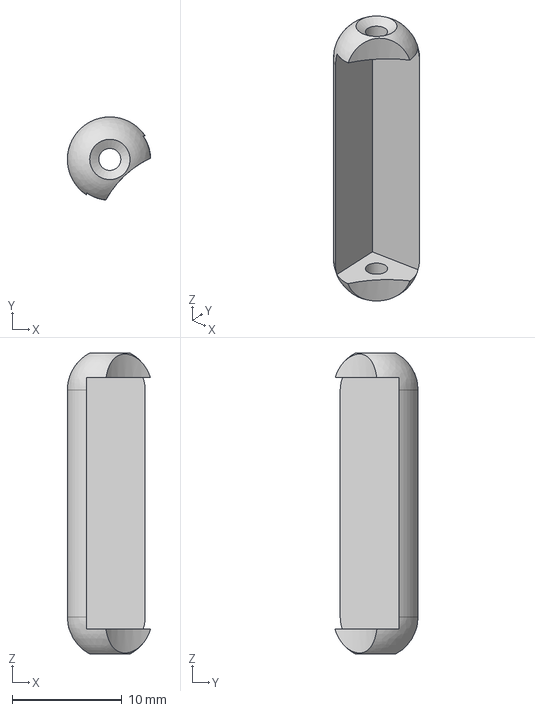
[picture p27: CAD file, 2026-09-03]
cad/step/zero_corners.step
7.60 x 7.58 x 27.4 mm

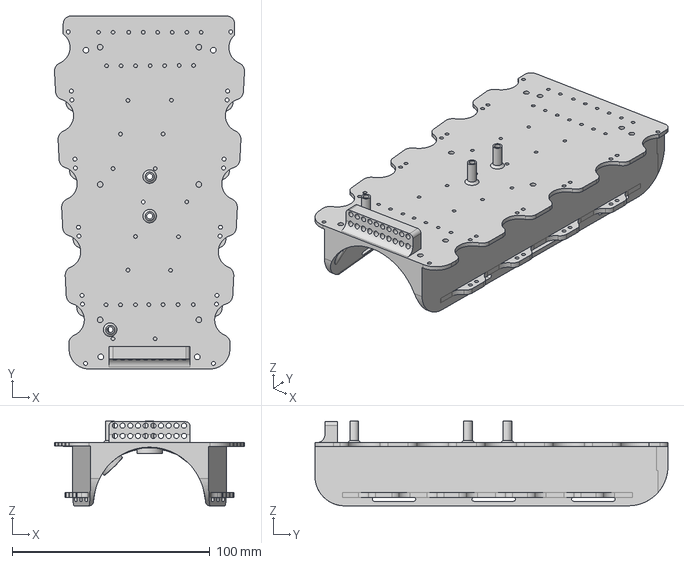
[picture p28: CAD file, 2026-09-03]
cad/step/zero_forearm_v5.step
96.2 x 178.7 x 42.8 mm

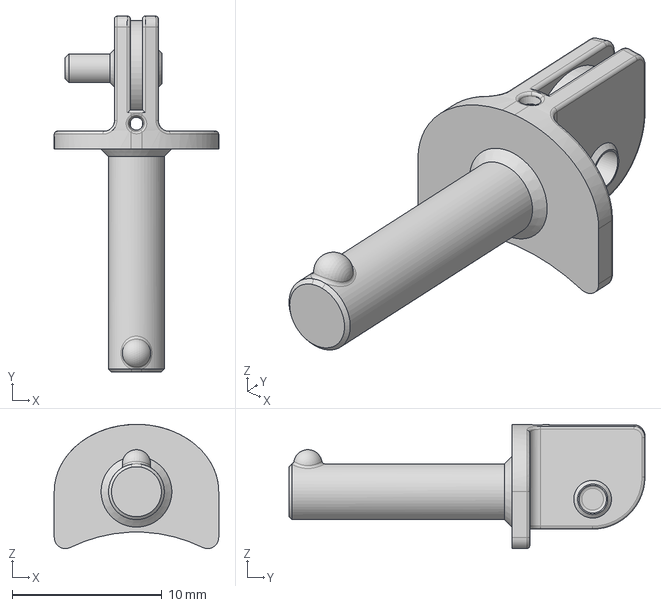
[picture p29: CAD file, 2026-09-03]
cad/step/zero_finger2_pip_thin_v3.step
11.0 x 23.8 x 8.30 mm

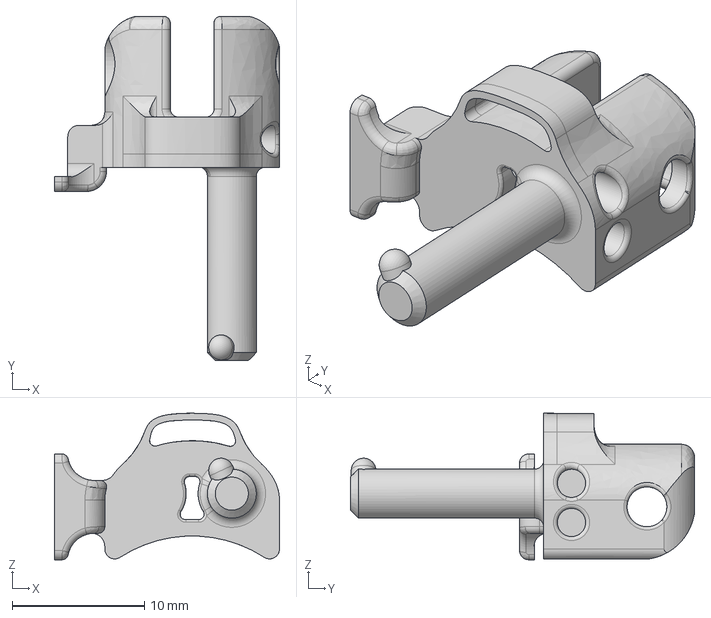
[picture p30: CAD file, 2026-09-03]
cad/step/zero_finger5_mcp_thick_v4.step
17.0 x 26.0 x 11.1 mm

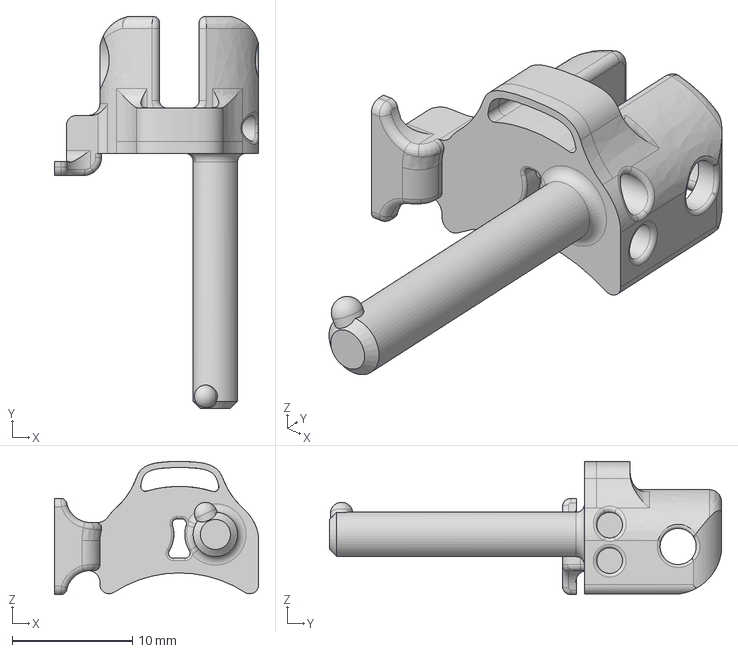
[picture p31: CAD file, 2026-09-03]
cad/step/zero_finger4_mcp_thick_v4.step
17.0 x 32.6 x 11.1 mm

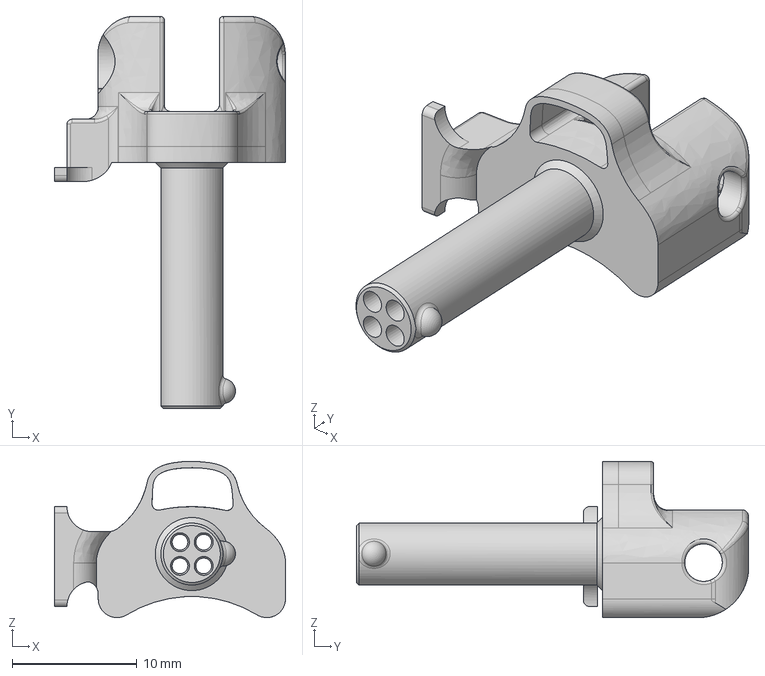
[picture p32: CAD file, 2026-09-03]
cad/step/zero_finger2_knuckle_v3.step
18.5 x 31.4 x 12.5 mm

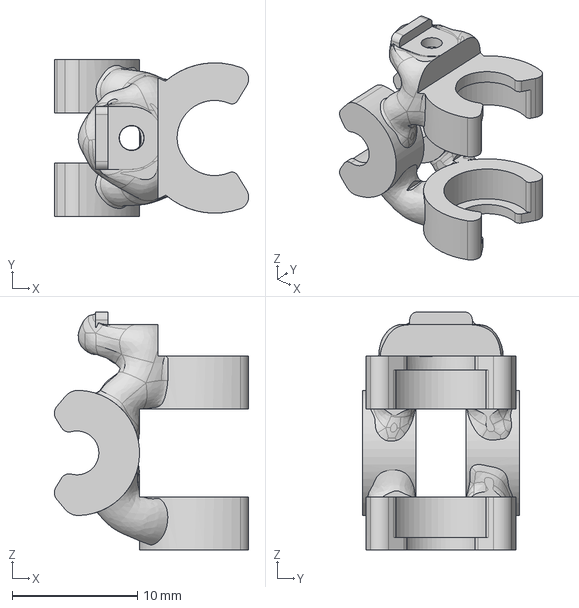
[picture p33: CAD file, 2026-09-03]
cad/step/zero_generated3.step
15.5 x 12.5 x 19.0 mm

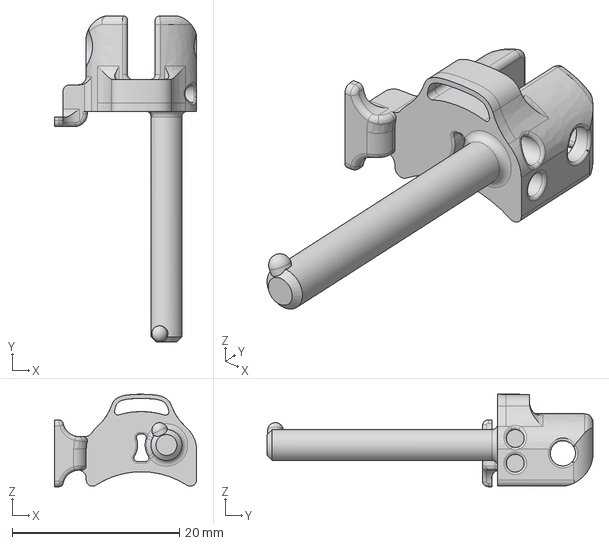
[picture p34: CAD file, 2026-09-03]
cad/step/zero_finger2_mcp_thick_v3.step
17.0 x 39.0 x 11.1 mm

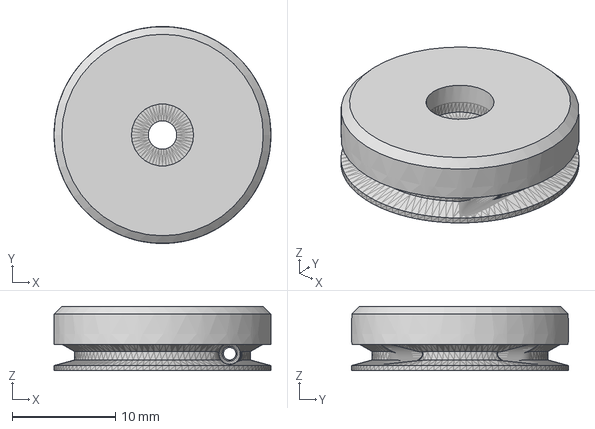
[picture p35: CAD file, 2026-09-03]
cad/step/spool_cover.step
21.0 x 21.0 x 6.23 mm

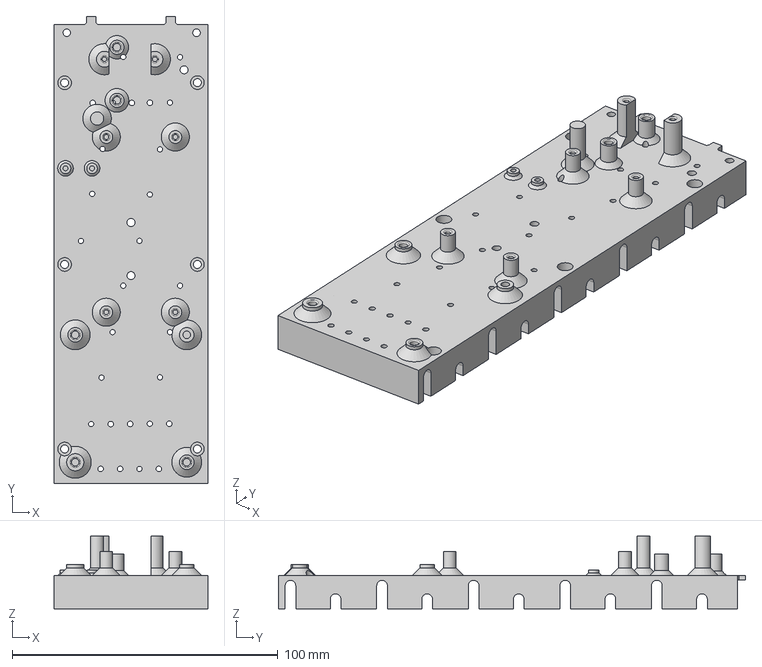
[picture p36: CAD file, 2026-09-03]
cad/step/zero_forearm_part2_v1.step
58.0 x 175.9 x 27.5 mm

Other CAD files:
cad/step/zero_heels.step
cad/step/zero_finger2_knuckle_thin_v3.step
cad/step/zero_generative1.step
cad/step/zero_finger3_knuckle_thin_v3.step
cad/step/zero_finger2_mcp_thin_v3.step
cad/step/zero_finger2_pip_center_v3.step
cad/step/zero_finger4_mcp_thin_v4.step
cad/step/zero_finger5_mcp_center_v3.step
cad/step/zero_finger5_mcp_thin_v4.step
cad/step/zero_palm_v3.step
cad/stl/spool_cover.stl
cad/stl/zero_corners.stl
cad/stl/zero_finger2_knuckle_thin_v3.stl
cad/stl/zero_finger2_knuckle_v3.stl
cad/stl/zero_finger2_mcp_center_v3.stl
cad/stl/zero_finger2_mcp_thick_v3.stl
cad/stl/zero_finger2_mcp_thin_v3.stl
cad/stl/zero_finger2_pip_center_v3.stl
cad/stl/zero_finger2_pip_thin_v3.stl
cad/stl/zero_finger3_knuckle_thin_v3.stl
cad/stl/zero_finger4_mcp_center_v3.stl
cad/stl/zero_finger4_mcp_thick_v4.stl
cad/stl/zero_finger4_mcp_thin_v4.stl
cad/stl/zero_finger5_mcp_center_v3.stl
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

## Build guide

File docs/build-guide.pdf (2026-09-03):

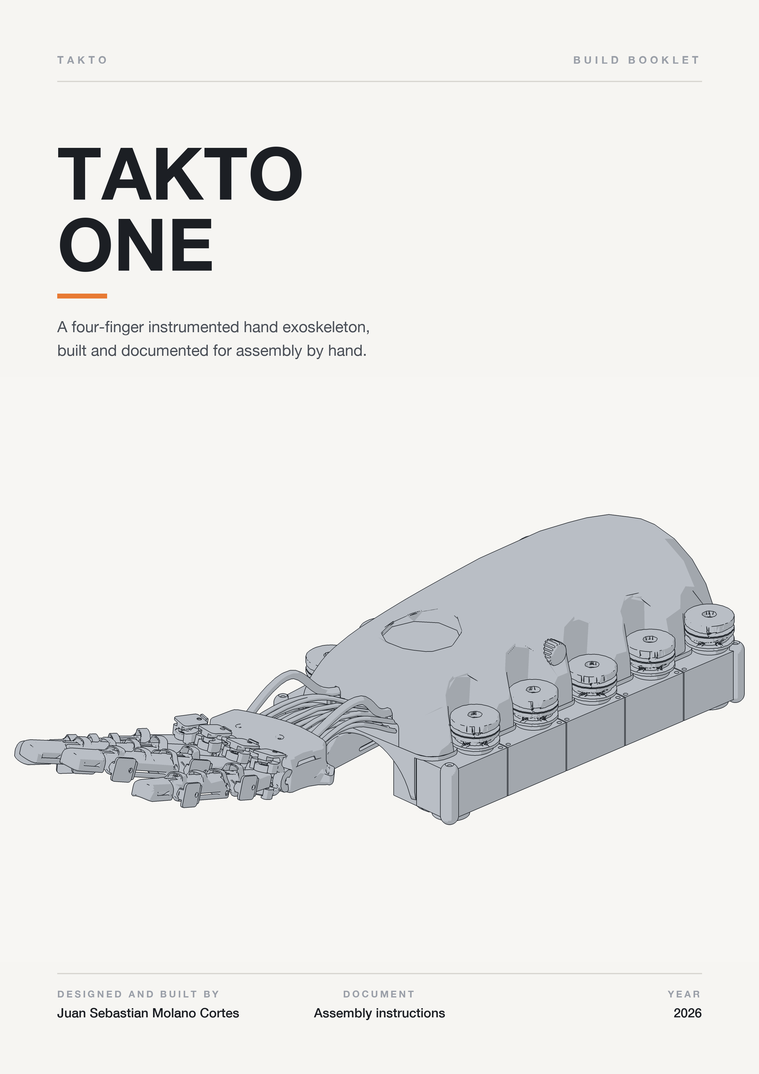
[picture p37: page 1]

HOW TO READ THIS

the part you add now

already built

Straight arrow push it that way

Curved arrow turn it that way

TURN + SLIDE | touch first, then turn
MOVES FREELY? | test before going on
DIAMETRIC ONLY | magnet orientation matters
AS BUILT: 2 OF 10 | budget, not design

Build one finger completely and check it moves before starting the other three. The finger chapter is drawn for the index; the other three are identical in sequence and differ only in link length.

2

1

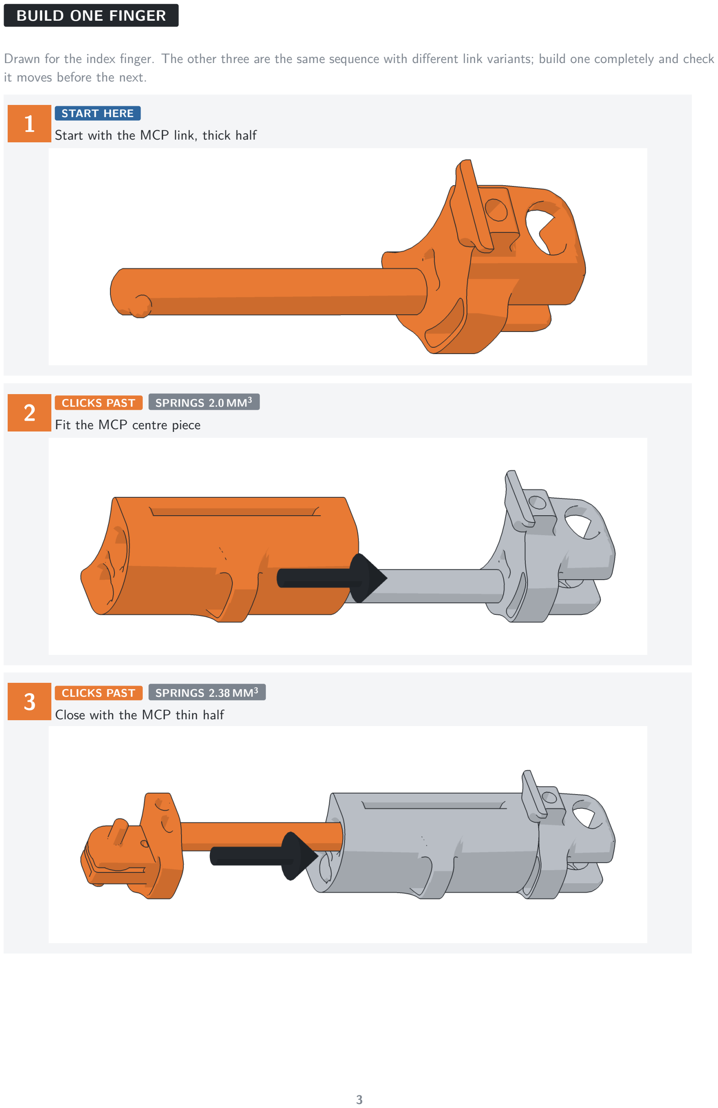
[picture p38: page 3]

BUILD ONE FINGER

Drawn for the index finger. The other three are the same sequence with different link variants; build one completely and check it moves before the next.

START HERE
Start with the MCP link, thick half

2

CLICKS PAST SPRINGS 2.0 MM³

Fit the MCP centre piece

3

CLICKS PAST SPRINGS 2.38 MM³

Close with the MCP thin half

3

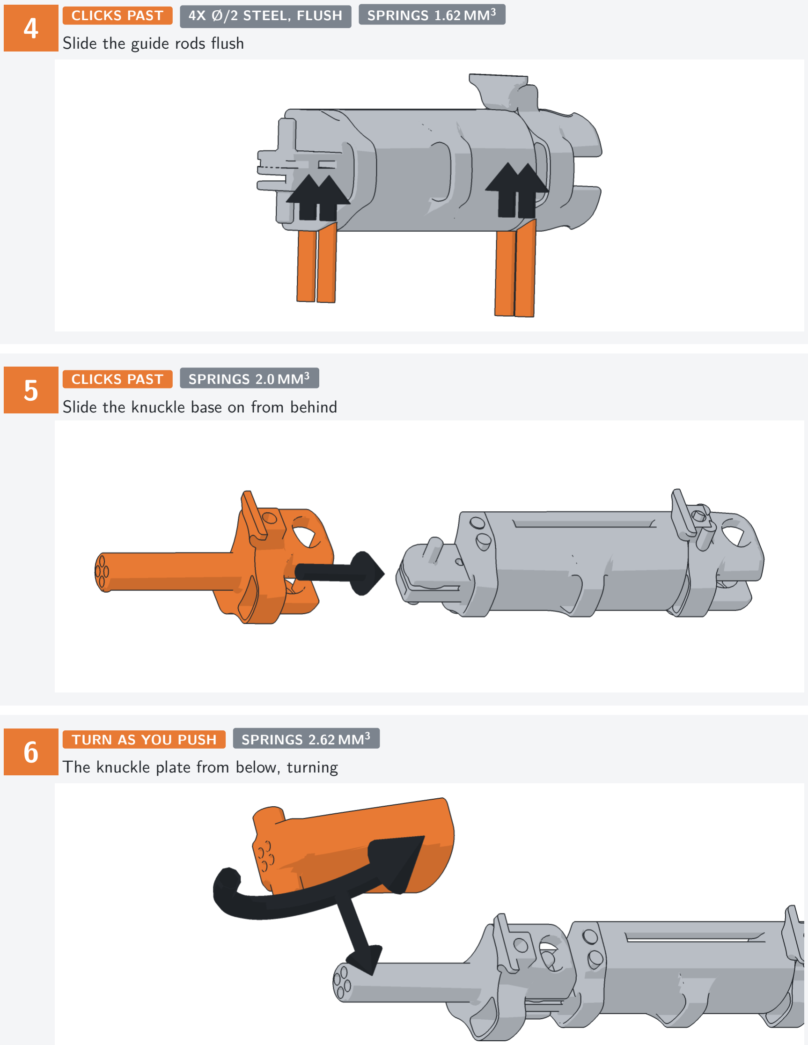
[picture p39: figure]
CLICKS PAST; 4X Ø/2 STEEL, FLUSH; SPRINGS 1.62 MM³; Slide the guide rods flush; SPRINGS 2.0 MM³; Slide the knuckle base on from behind; TURN AS YOU PUSH; SPRINGS 2.62 MM³; The knuckle plate from below, turning

4

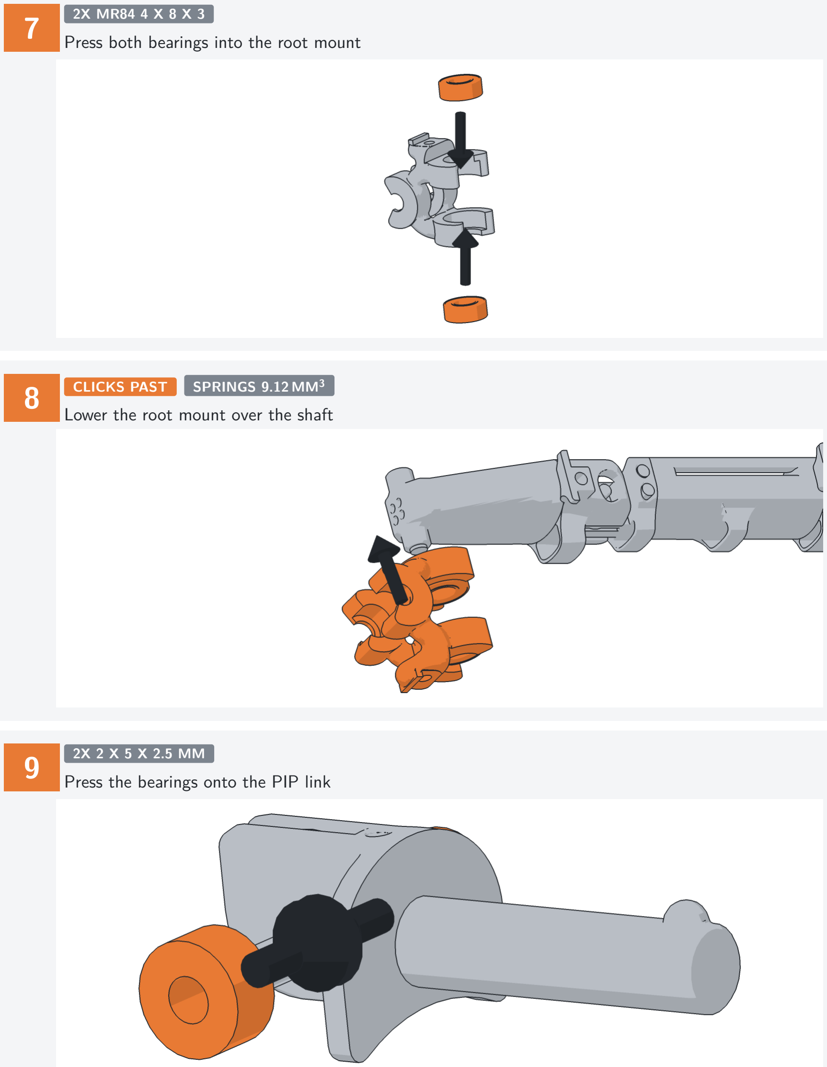
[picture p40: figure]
Press both bearings into the root mount; CLICKS PAST; SPRINGS 9.12 MM³; Lower the root mount over the shaft; Press the bearings onto the PIP link

5

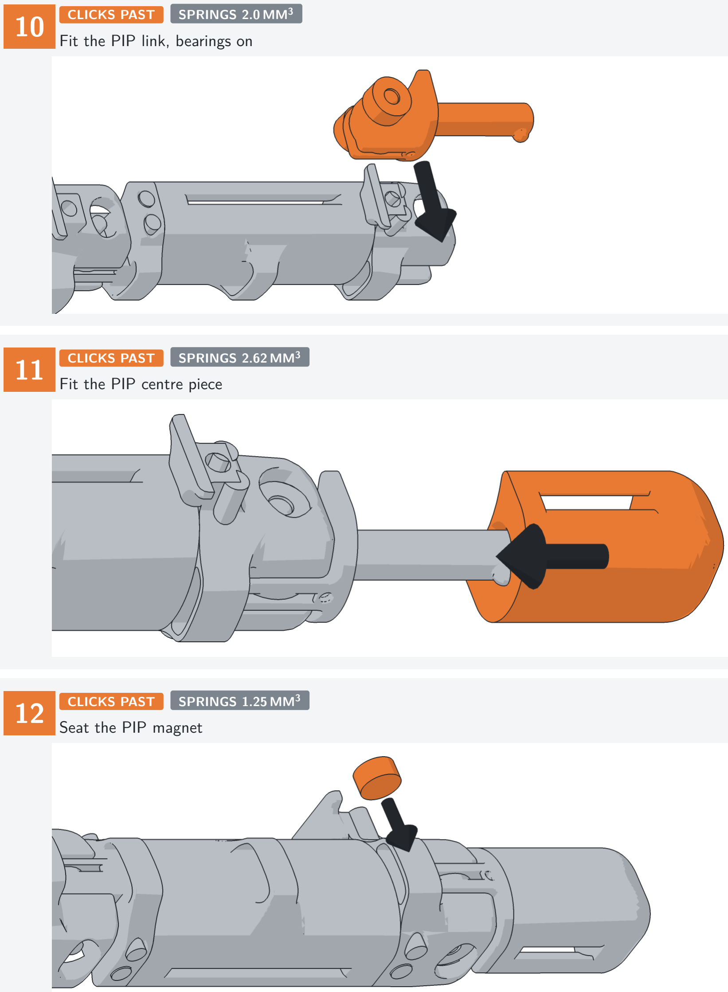
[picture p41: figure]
CLICKS PAST; SPRINGS 2.0 MM³; Fit the PIP link, bearings on; SPRINGS 2.62 MM³; Fit the PIP centre piece; SPRINGS 1.25 MM³; Seat the PIP magnet

6

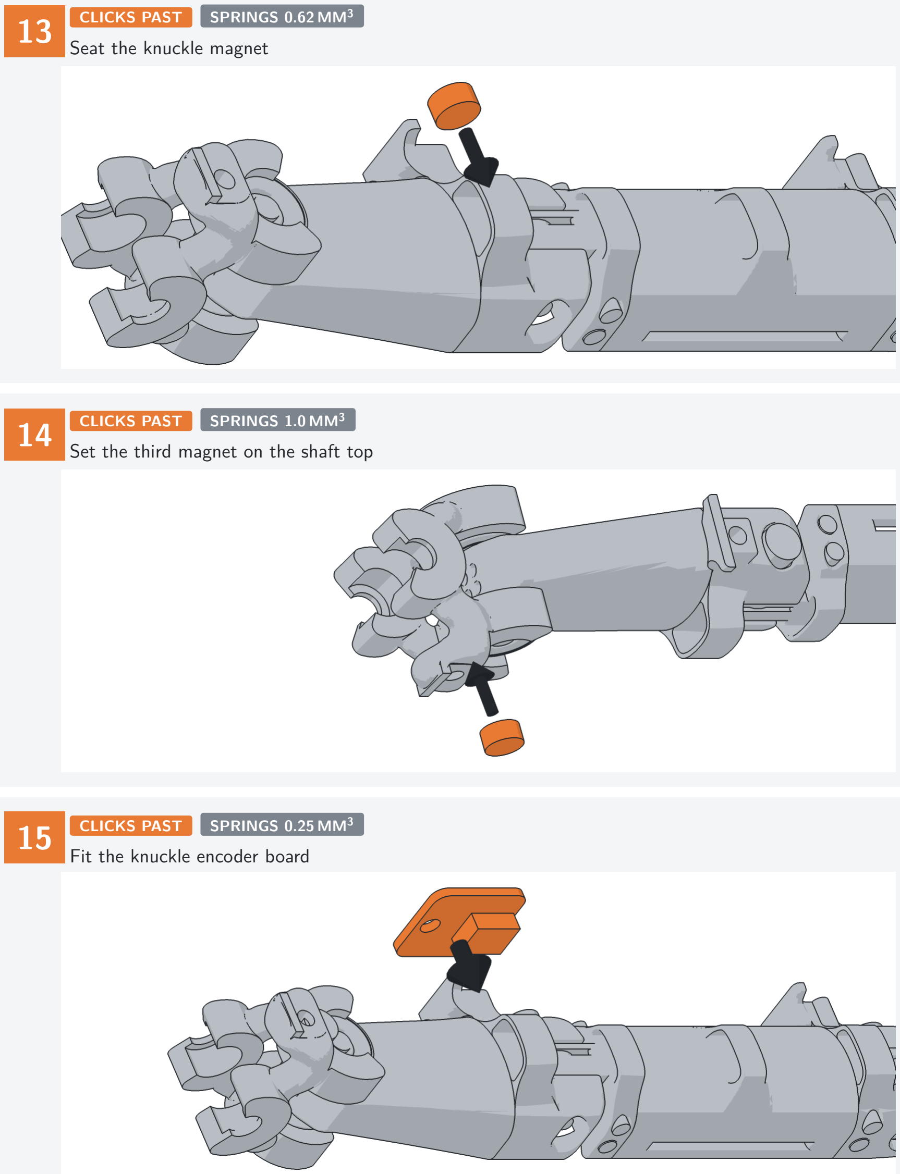
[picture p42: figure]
CLICKS PAST; SPRINGS 0.62 MM³; Seat the knuckle magnet; SPRINGS 1.0 MM³; Set the third magnet on the shaft top; SPRINGS 0.25 MM³; Fit the knuckle encoder board

7

### 16 Fit the MCP encoder board

### 17 Fit the PIP encoder board

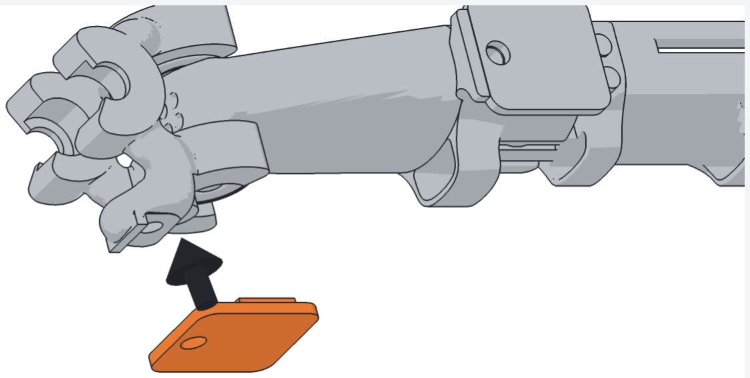
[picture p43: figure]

8

1

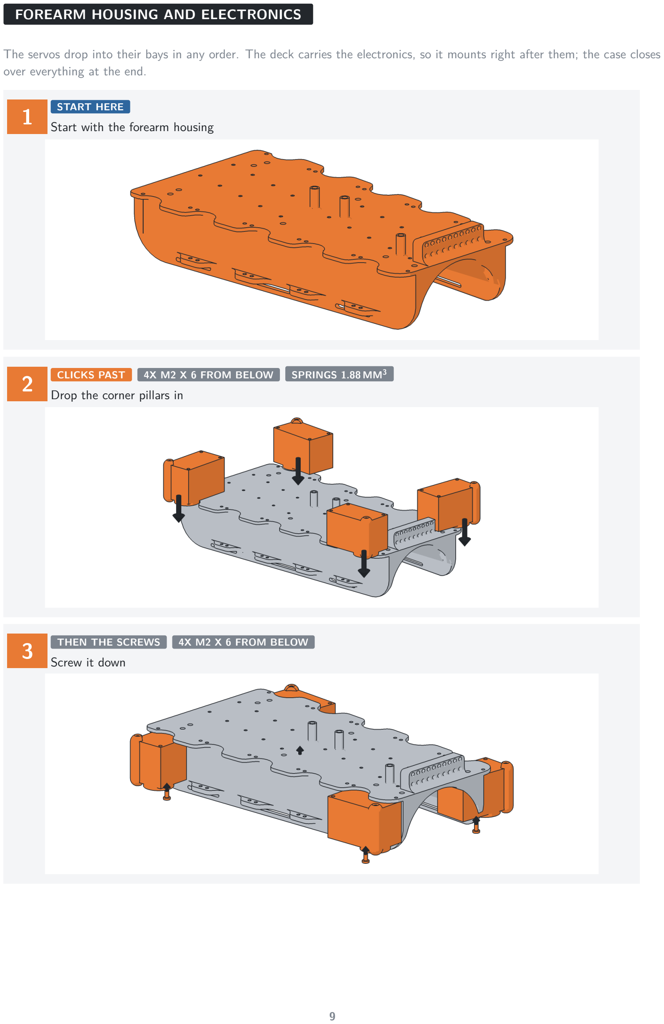
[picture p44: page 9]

FOREARM HOUSING AND ELECTRONICS

The servos drop into their bays in any order. The deck carries the electronics, so it mounts right after them; the case closes over everything at the end.

START HERE
Start with the forearm housing

2

CLICKS PAST | 4X M2 X 6 FROM BELOW | SPRINGS 1.88 MM³

Drop the corner pillars in

3

THEN THE SCREWS 4X M2 X 6 FROM BELOW
Screw it down

9

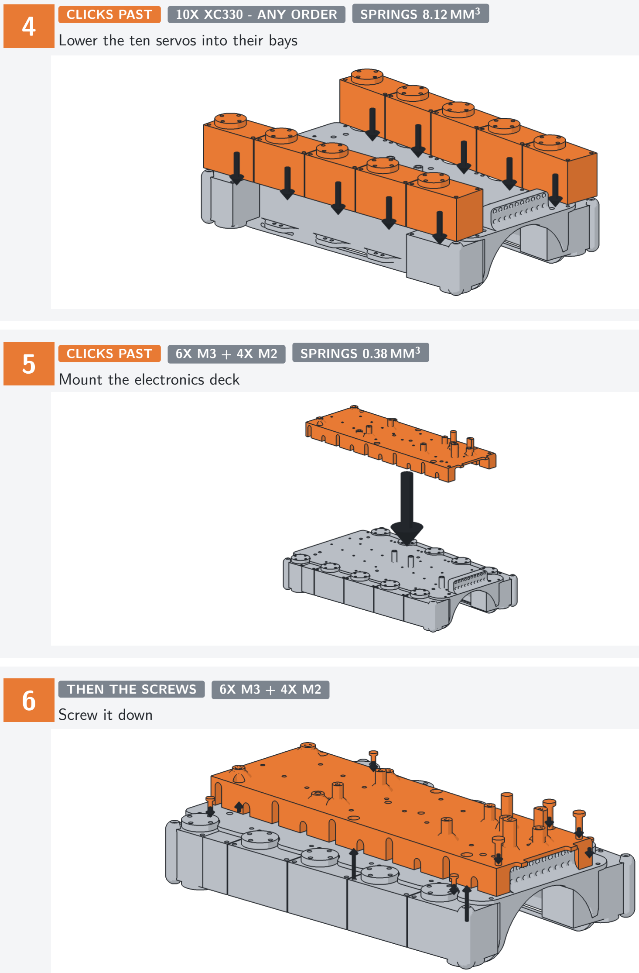
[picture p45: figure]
CLICKS PAST; 10X XC330 - ANY ORDER; SPRINGS 8.12 MM³; Lower the ten servos into their bays; SPRINGS 0.38 MM³; Mount the electronics deck; THEN THE SCREWS; Screw it down

10

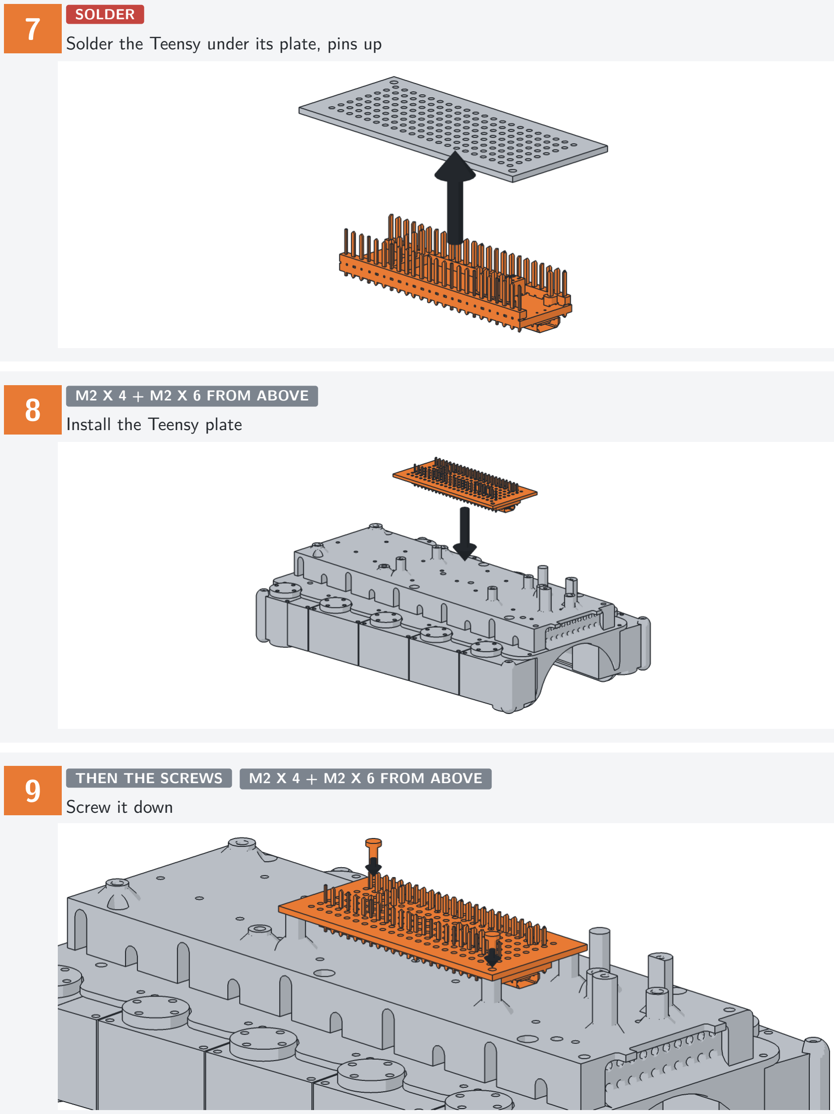
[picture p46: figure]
SOLDER; M2 X 4 + M2 X 6 FROM ABOVE; Install the Teensy plate; Screw it down

Solder the Teensy under its plate, pins up

THEN THE SCREWS M2 X 4 + M2 X 6 FROM ABOVE

11

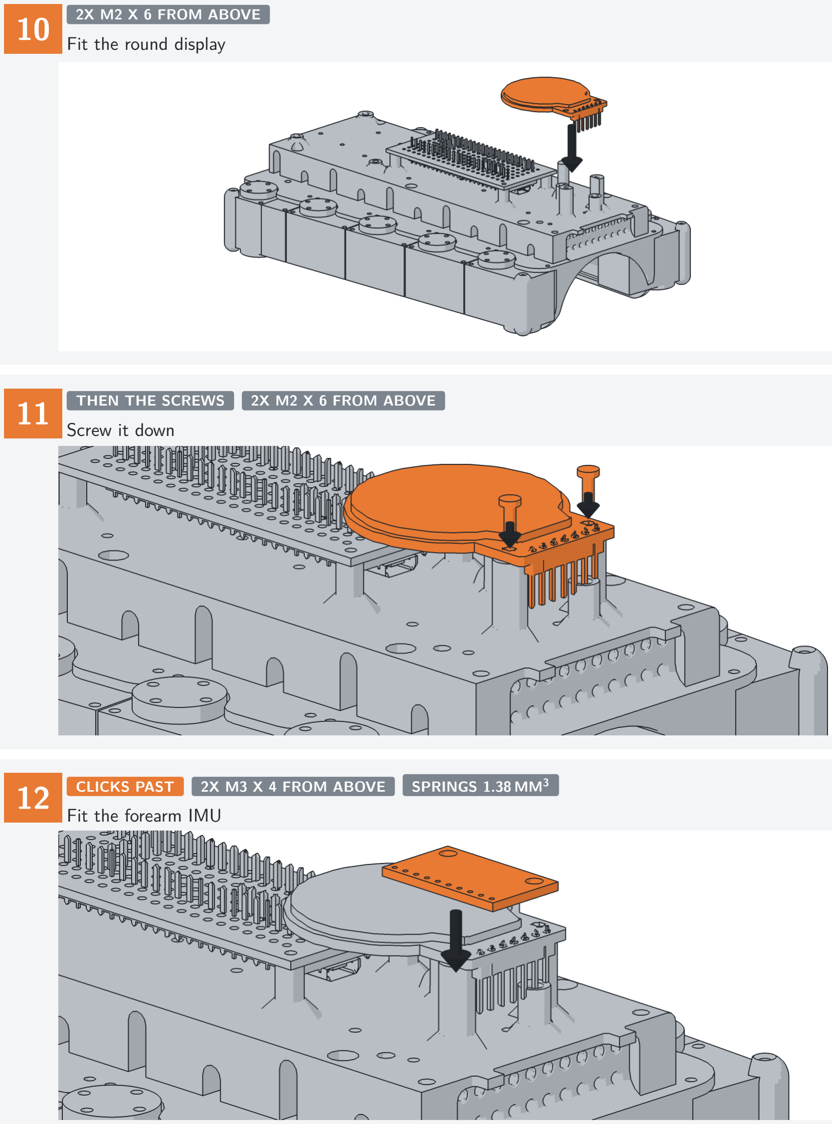
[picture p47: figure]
10 2X M2 X 6 FROM ABOVE; Fit the round display; THEN THE SCREWS; 2X M2 X 6 FROM ABOVE; Screw it down; Fit the forearm IMU

12 | CLICKS PAST | 2X M3 X 4 FROM ABOVE | SPRINGS 1.38 MM³

12

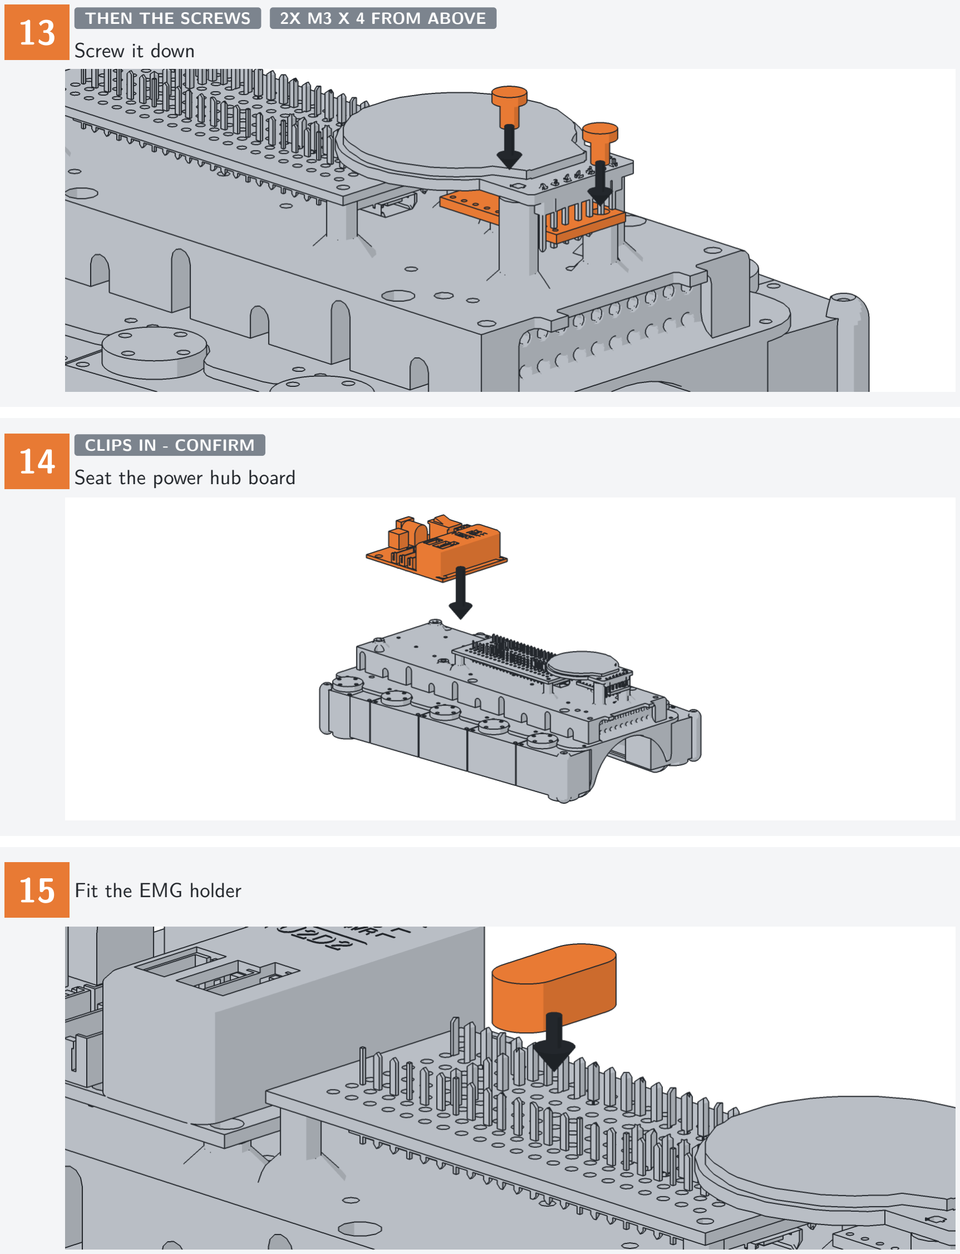
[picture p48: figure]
THEN THE SCREWS; 2X M3 X 4 FROM ABOVE; Screw it down; 14 CLIPS IN - CONFIRM; Seat the power hub board; 15 Fit the EMG holder

13

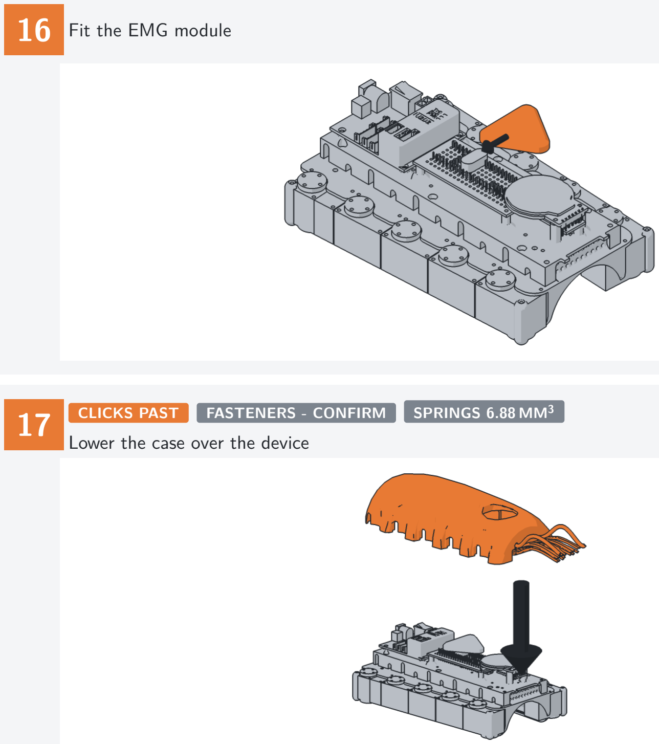
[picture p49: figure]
16 Fit the EMG module; CLICKS PAST; FASTENERS - CONFIRM; SPRINGS 6.88 MM³; Lower the case over the device

14

1

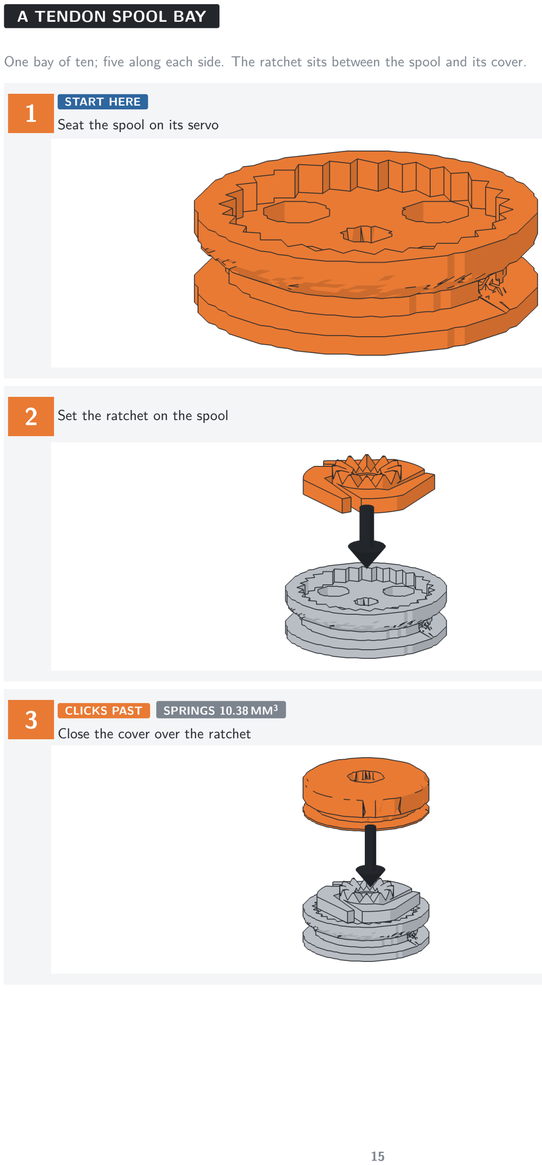
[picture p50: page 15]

A TENDON SPOOL BAY

One bay of ten; five along each side. The ratchet sits between the spool and its cover.

START HERE
Seat the spool on its servo

### 2 Set the ratchet on the spool

3

CLICKS PAST SPRINGS 10.38 MM³

Close the cover over the ratchet

15

1

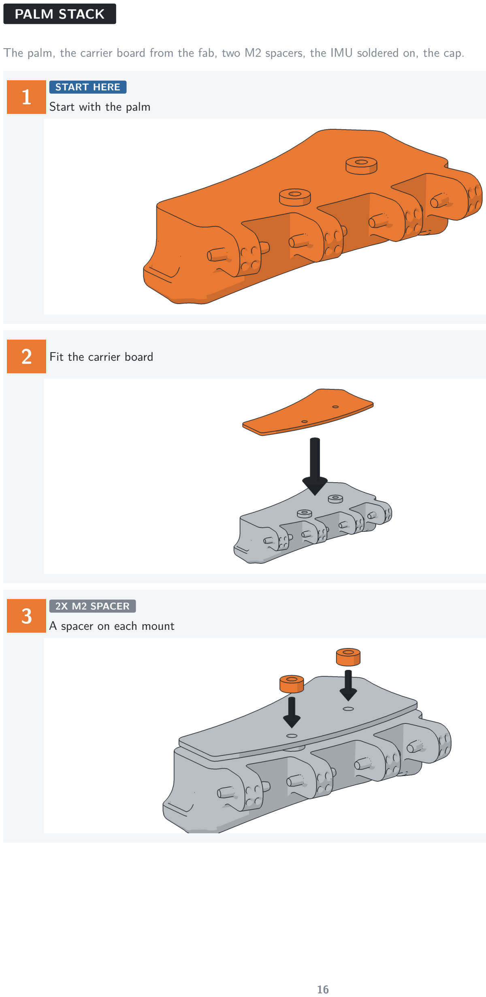
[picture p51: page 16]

PALM STACK

The palm, the carrier board from the fab, two M2 spacers, the IMU soldered on, the cap.

START HERE
Start with the palm

### 2 Fit the carrier board

3

2X M2 SPACER
A spacer on each mount

16

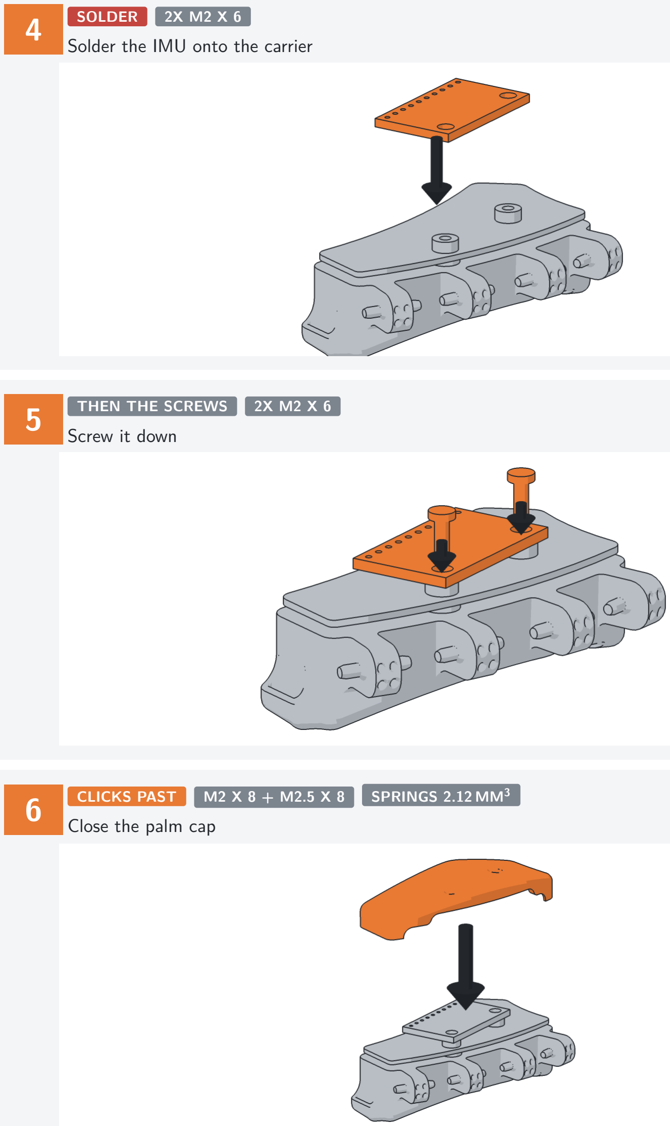
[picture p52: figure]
SOLDER; Solder the IMU onto the carrier; THEN THE SCREWS; Screw it down; Close the palm cap

CLICKS PAST | M2 X 8 + M2.5 X 8 | SPRINGS 2.12 MM³

17

7

THEN THE SCREWS M2 X 8 + M2.5 X 8
Screw it down

18

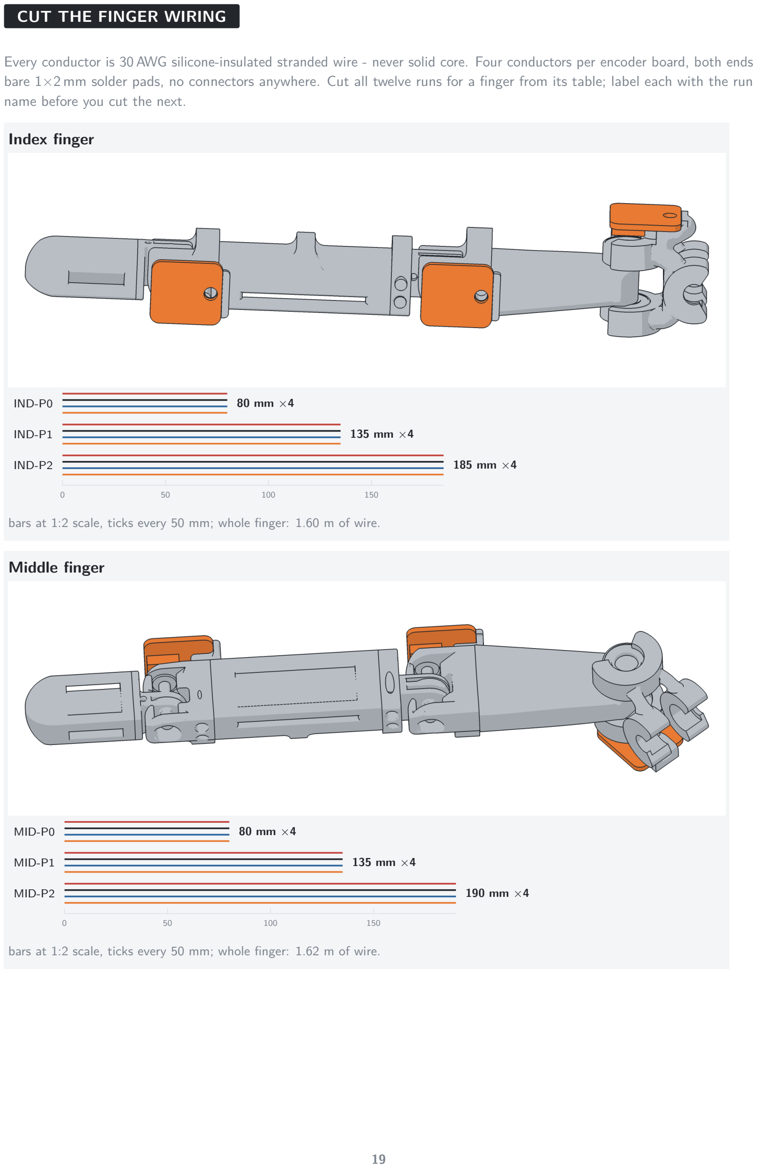
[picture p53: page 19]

CUT THE FINGER WIRING

Every conductor is 30 AWG silicone-insulated stranded wire - never solid core. Four conductors per encoder board, both ends bare 1×2 mm solder pads, no connectors anywhere. Cut all twelve runs for a finger from its table; label each with the run name before you cut the next.

Index finger

IND-P2 | 185 mm ×4
IND-P1 | 135 mm ×4
IND-P0 | 80 mm ×4
0 | 50 | 100 | 150

bars at 1:2 scale, ticks every 50 mm; whole finger: 1.60 m of wire.

Middle finger

MID-P2 | 190 mm ×4
MID-P1 | 135 mm ×4
MID-P0 | 80 mm ×4
0 | 50 | 100 | 150

bars at 1:2 scale, ticks every 50 mm; whole finger: 1.62 m of wire.

19

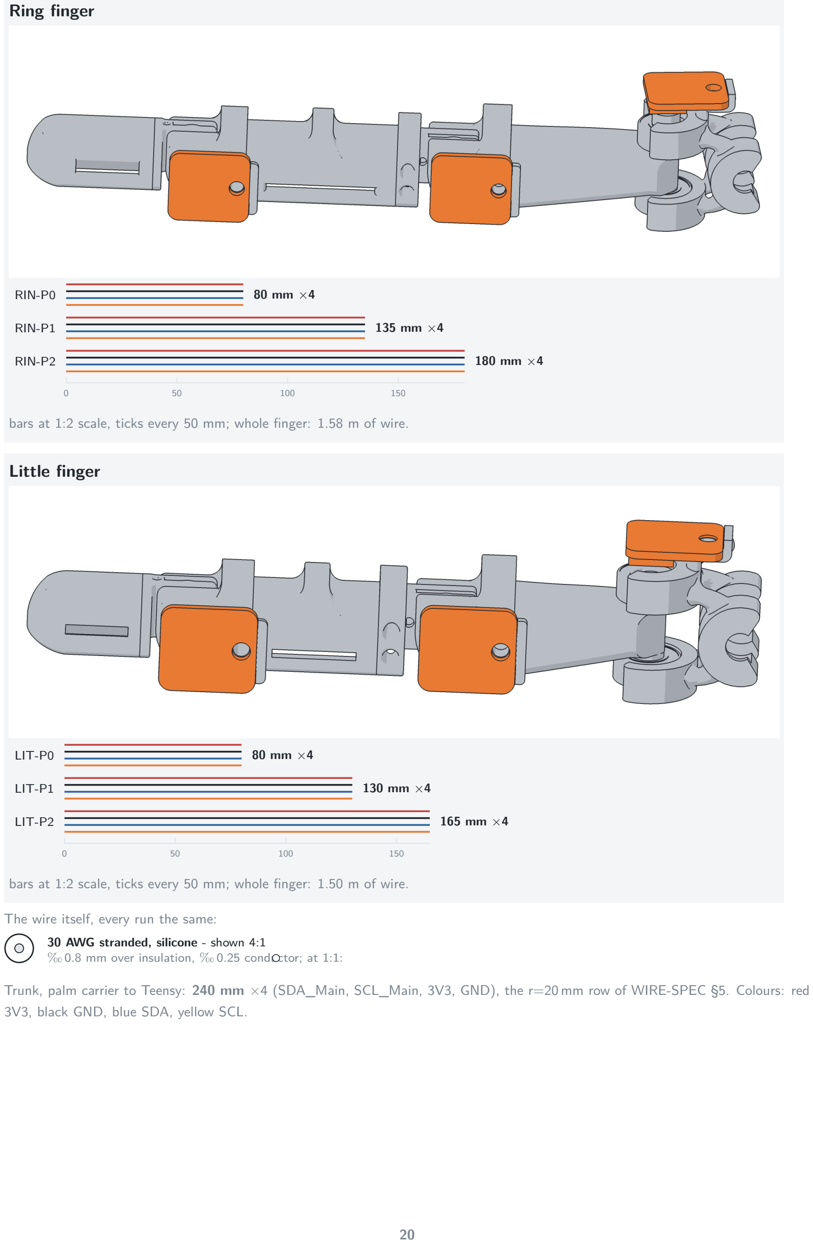
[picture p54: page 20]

Ring finger

RIN-P2 | 180 mm ×4
RIN-P1 | 135 mm ×4
RIN-P0 | 80 mm ×4
0 | 50 | 100 | 150

bars at 1:2 scale, ticks every 50 mm; whole finger: 1.58 m of wire.

Little finger

LIT-P2 | 165 mm ×4
LIT-P1 | 130 mm ×4
LIT-P0 | 80 mm ×4
0 | 50 | 100 | 150

bars at 1:2 scale, ticks every 50 mm; whole finger: 1.50 m of wire.

The wire itself, every run the same:

### 30 AWG stranded, silicone - shown 4:1

‰0.8 mm over insulation, ‰0.25 conductor; at 1:1:

Trunk, palm carrier to Teensy: 240 mm ×4 (SDA_Main, SCL_Main, 3V3, GND), the r=20 mm row of WIRE-SPEC §5. Colours: red 3V3, black GND, blue SDA, yellow SCL.

20

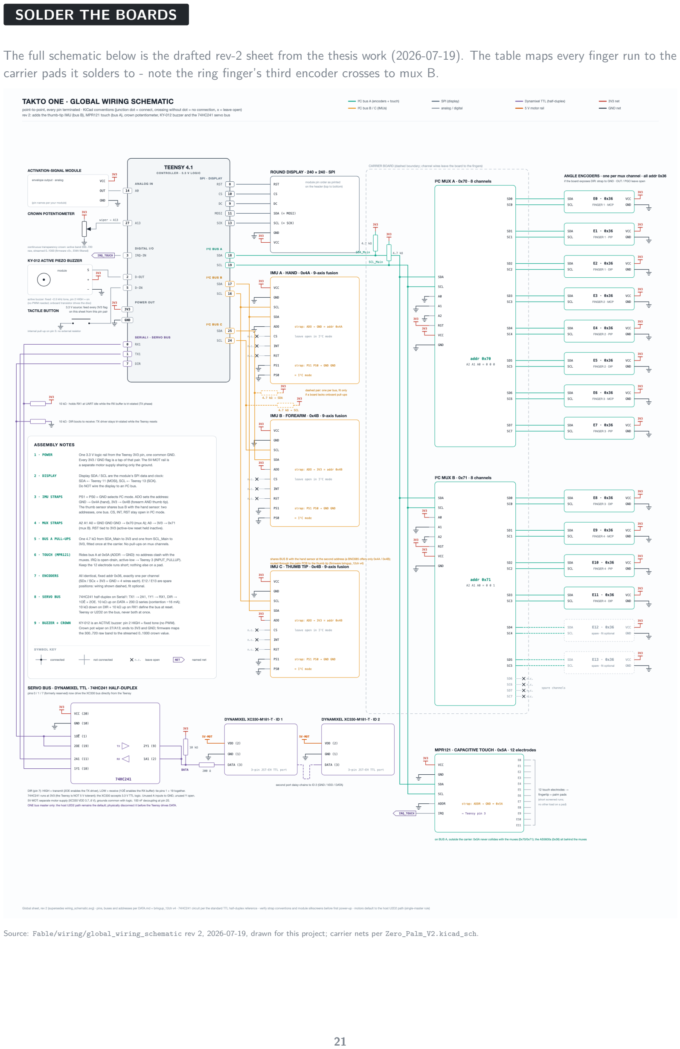
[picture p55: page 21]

SOLDER THE BOARDS

The full schematic below is the drafted rev-2 sheet from the thesis work (2026-07-19). The table maps every finger run to the carrier pads it solders to - note the ring finger’s third encoder crosses to mux B.

Source: Fable/wiring/global_wiring_schematic rev 2, 2026-07-19, drawn for this project; carrier nets per Zero_Palm_V2.kicad_sch.

21

WHERE EACH RUN LANDS

Every encoder is the same board at address 0x36; the mux channel is what tells them apart. Solder the run’s SDA (blue) and SCL (yellow) to the listed channel pads on the carrier, 3V3 (red) and GND (black) to the rail pads beside them. Both ends are bare 1×2 mm pads - no connectors.

run | encoder | mux | carrier pads
IND-P0 | E0 | A·0x70 | SD0/SC0
IND-P1 | E1 | A·0x70 | SD1/SC1
IND-P2 | E2 | A·0x70 | SD2/SC2
MID-P0 | E3 | A·0x70 | SD3/SC3
MID-P1 | E4 | A·0x70 | SD4/SC4
MID-P2 | E5 | A·0x70 | SD5/SC5
RIN-P0 | E6 | A·0x70 | SD6/SC6
RIN-P1 | E7 | A·0x70 | SD7/SC7
RIN-P2 | E8 | B·0x71 | SD0/SC0 | ← crosses to B
LIT-P0 | E9 | B·0x71 | SD1/SC1
LIT-P1 | E10 | B·0x71 | SD2/SC2
LIT-P2 | E11 | B·0x71 | SD3/SC3
E12/E13 = spare channels (mux B SD4/SC4, SD5/SC5), left open

Encoder board, both ends alike

AS5600

3V3

GND

SDA

SCL

The palm IMU (BNO085, 0x4A) is a soldered joint onto the carrier (correction A13), on I²C bus B - not behind the

muxes. Then its two M2×6 screws through the spacers.

22

THE FINISHED DEVICE

All four fingers built and instrumented, the case on. Every view on this page is rendered from the same CAD you just assembled.

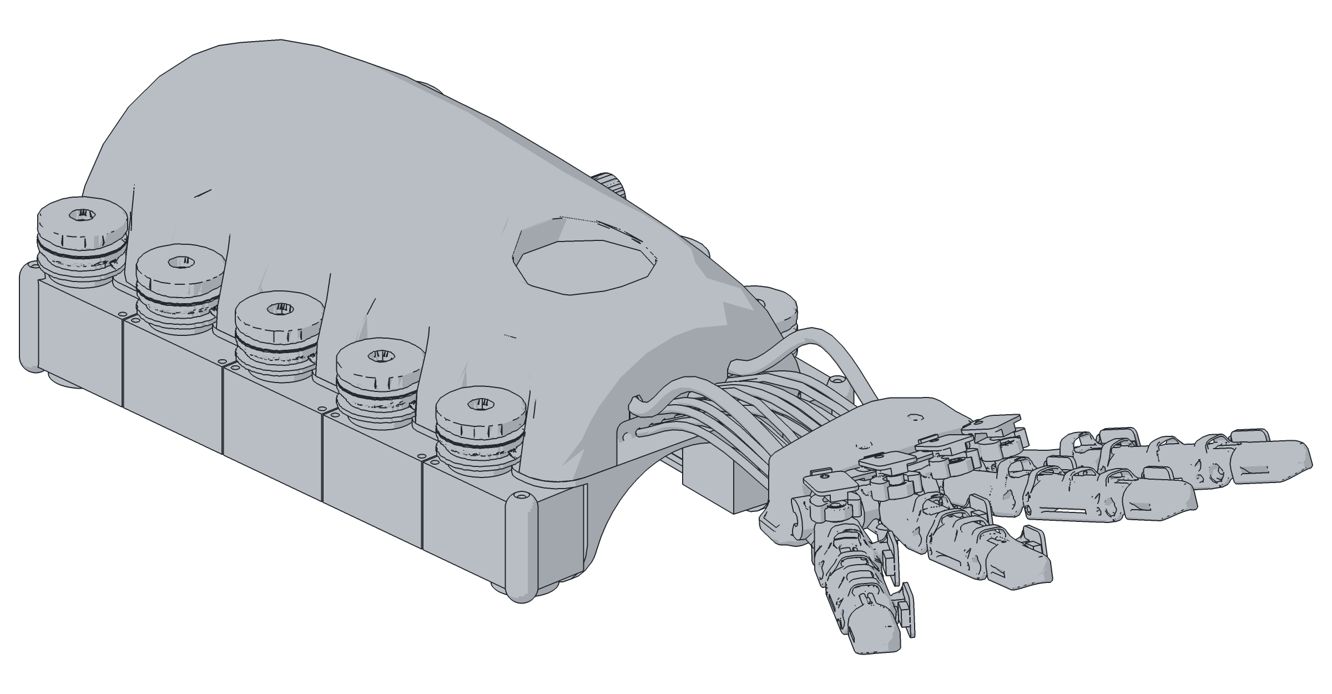
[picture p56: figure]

Three-quarter view, case on.

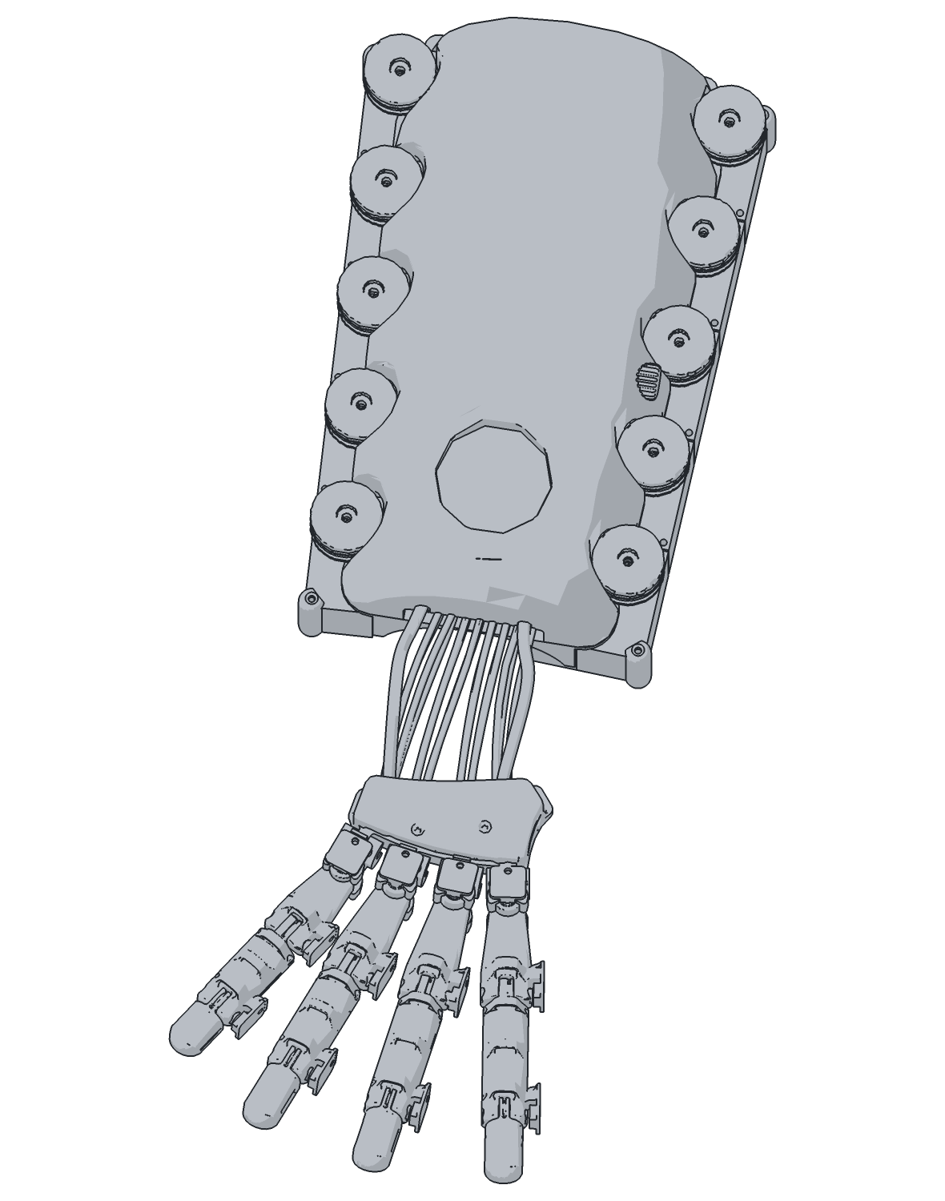
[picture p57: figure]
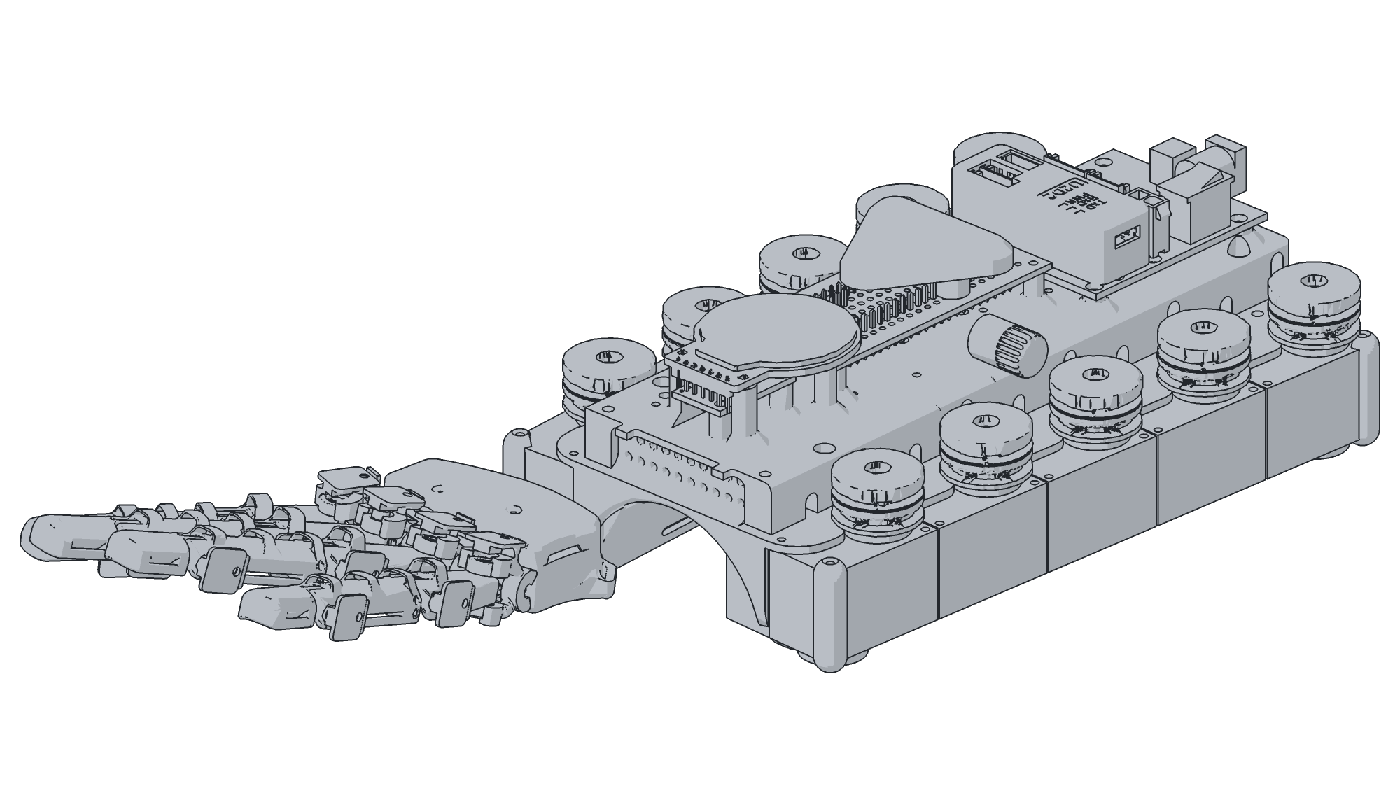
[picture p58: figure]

From above: the four digits and their spread. | Case off: the electronics deck and the spool bays.
4 long fingers built and instrumented | · 12 magnetic encoders | · 10 tendon-spool bays | · 2 XC330 servos fitted | · 100 %
PETG as built

The housing is drilled and wired for eight servos across the four fingers, with two bays held for a future thumb. Two are fitted here: that is a budget limit, not a design one, and the spool bays, wiring and firmware already scale to the full count. The motor bus is owned by the host PC through a U2D2; the Teensy senses only.

23

CHECK YOUR PARTS AGAINST THESE

Print this page at 100 % and lay each real part on its outline. The grey bar at the bottom must measure exactly 50 mm; if it does not, your printer scaled the page.

AS5600 board

10.5 × 11.5 mm · 4 pads

MCP bearing MR84

∅8 / bore ∅4 × 3 mm

PIP bearing

∅5 / bore ∅2 × 2.5 mm

Magnet

∅4 × 2 mm, diametric

M2 spacer

∅4.5 / ∅2 × 2 mm

Guide rod, MCP

∅2 × 13.2 mm · 2x

Guide rod, PIP

∅2 × 16 mm · 2x

M2 x 4

1x · Teensy plate

M2 x 6

13x · everywhere

M2 x 8

1x · palm cap

M3 x 4

2x · forearm IMU

M2.5 x 8

1x · palm cap

M3 x 16

6x · electronics deck

Tendon spool

∅17 outline · 10 bays

Wire, 30 AWG

∅1.2 insulated

exactly 50 mm at 100 %

24

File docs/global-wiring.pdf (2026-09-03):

# TAKTO ONE · GLOBAL WIRING SCHEMATIC

point-to-point, every pin terminated · KiCad conventions (junction dot = connect, crossing without dot = no connection, x = leave open) rev 2: adds the thumb-tip IMU (bus B), MPR121 touch (bus A), crown potentiometer, KY-012 buzzer and the 74HC241 servo bus

I²C bus A (encoders + touch)

I²C bus B / C (IMUs)

SPI (display)

analog / digital

Dynamixel TTL (half-duplex)

5 V motor rail

3V3 net

GND net

# TEENSY 4.1

CONTROLLER · 3.3 V LOGIC

RST | 8
CS | 10
DC | 9
MOSI | 11
SCK | 13
SDA | 18
SCL | 19
SDA | 17
SCL | 16
SDA | 25
SCL | 24

SPI · DISPLAY

I²C BUS A

I²C BUS B

I²C BUS C

### 14 A0

### 27 A13

### 3 IRQ-IN

### 2 D-OUT

### 5 D-IN

3V3

GND

### 0 RX1

### 1 TX1

### 7 DIR

ANALOG IN

DIGITAL I/O

POWER OUT

SERIAL1 · SERVO BUS

3V3
3.3 V source: feed every 3V3 flag on this sheet from this pin pair

IRQ_TOUCH

## ROUND DISPLAY · 240 × 240 · SPI

RST

CS

DC

SDA (= MOSI)

SCL (= SCK)

GND

VCC

3V3

module pin order as printed on the header (top to bottom)

## IMU A · HAND · 0x4A · 9-axis fusion

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
strap: ADO → GND = addr 0x4A

n.c.

n.c.

n.c.

leave open in I²C mode

strap: PS1 PS0 → GND GND

= I²C mode

## IMU B · FOREARM · 0x4B · 9-axis fusion

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
strap: ADO → 3V3 = addr 0x4B

n.c.

n.c.

n.c.

leave open in I²C mode

strap: PS1 PS0 → GND GND

= I²C mode

## IMU C · THUMB TIP · 0x4B · 9-axis fusion

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
strap: ADO → 3V3 = addr 0x4B

n.c.

n.c.

n.c.

leave open in I²C mode

strap: PS1 PS0 → GND GND

= I²C mode

shares BUS B with the hand sensor at the second address (a BNO085 offers only 0x4A / 0x4B); routed through the palm PCB to the thumb tip (firmware bringup_12ch v4)

3V3

4.7 kΩ → SDA | 3V3

### 4.7 kΩ → SCL

dashed pair: one per bus, fit only if a board lacks onboard pull-ups

## ACTIVATION-SIGNAL MODULE

envelope output · analog | VCC

OUT

GND

3V3

(pin names per your module)

## CROWN POTENTIOMETER

3V3

wiper → A13

continuous transparency crown: active band 300..720 raw, streamed 0..1000 (firmware v3+, EMA filtered)

## KY-012 ACTIVE PIEZO BUZZER

module | S

+

−

3V3

active buzzer: fixed ~2.5 kHz tone, pin 2 HIGH = on (no PWM needed; onboard transistor drives the disc)

## TACTILE BUTTON

internal pull-up on pin 5: no external resistor

SDA_Main

SCL_Main

3V3

### 4.7 kΩ

3V3

### 4.7 kΩ

## I²C MUX A · 0x70 · 8 channels

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
## addr 0x70

A2 A1 A0 = 0 0 0

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
## I²C MUX B · 0x71 · 8 channels

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
## addr 0x71

A2 A1 A0 = 0 0 1

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
SD6 | n.c.
SC6 | n.c.
SD7 | n.c.
SC7 | n.c.

spare channels

## ANGLE ENCODERS · one per mux channel · all addr 0x36

if the board exposes DIR: strap to GND · OUT / PGO leave open

E0 · 0x36

FINGER 1 · MCP

SDA
SCL

VCC

3V3

GND

E1 · 0x36

FINGER 1 · PIP

SDA
SCL

VCC

3V3

GND

E2 · 0x36

FINGER 1 · DIP

SDA
SCL

VCC

3V3

GND

E3 · 0x36

FINGER 2 · MCP

SDA
SCL

VCC

3V3

GND

E4 · 0x36

FINGER 2 · PIP

SDA
SCL

VCC

3V3

GND

E5 · 0x36

FINGER 2 · DIP

SDA
SCL

VCC

3V3

GND

E6 · 0x36

FINGER 3 · MCP

SDA
SCL

VCC

3V3

GND

E7 · 0x36

FINGER 3 · PIP

SDA
SCL

VCC

3V3

GND

E8 · 0x36

FINGER 3 · DIP

SDA
SCL

VCC

3V3

GND

E9 · 0x36

FINGER 4 · MCP

SDA
SCL

VCC

3V3

GND

E10 · 0x36

FINGER 4 · PIP

SDA
SCL

VCC

3V3

GND

E11 · 0x36

FINGER 4 · DIP

SDA
SCL

VCC

3V3

GND

E12 · 0x36

spare · fit optional

SDA
SCL

VCC

3V3

GND

E13 · 0x36

spare · fit optional

SDA
SCL

VCC

3V3

GND

CARRIER BOARD (dashed boundary; channel wires leave the board to the fingers)

## MPR121 · CAPACITIVE TOUCH · 0x5A · 12 electrodes

VCC

GND

SDA

SCL

ADDR

IRQ

3V3

IRQ_TOUCH

strap: ADDR → GND = 0x5A

→ Teensy pin 3

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
12 touch electrodes →
fingertip + palm pads
(short screened runs;
no other load on a pad)

on BUS A, outside the carrier: 0x5A never collides with the muxes (0x70/0x71); the AS5600s (0x36) sit behind the muxes

## SERVO BUS · DYNAMIXEL TTL · 74HC241 HALF-DUPLEX

pins 0 / 1 / 7 (formerly reserved) now drive the XC330 bus directly from the Teensy

74HC241

VCC (20)

GND (10)

1OE̅ (1)

2OE (19)

2A1 (11)

1Y1 (18)

3V3

2Y1 (9)

1A1 (2)

TX

RX

3V3

### 10 kΩ

DATA

## DYNAMIXEL XC330-M181-T · ID 1

VDD (2)

GND (1)

DATA (3)

5V·MOT

3-pin JST-EH TTL port

## DYNAMIXEL XC330-M181-T · ID 2

VDD (2)

GND (1)

DATA (3)

5V·MOT

3-pin JST-EH TTL port

second port daisy-chains to ID 2 (GND / VDD / DATA) DIR (pin 7): HIGH = transmit (2OE enables the TX driver), LOW = receive (1OE̅enables the RX buffer): tie pins 1 + 19 together. 74HC241 runs at 3V3 (the Teensy is NOT 5 V tolerant); the XC330 accepts 3.3 V TTL logic. Unused A inputs to GND, unused Y open. 5V·MOT: separate motor supply (XC330 VDD 3.7..6 V), grounds common with logic. 100 nF decoupling at pin 20.
ONE bus master only: the host U2D2 path remains the default; physically disconnect it before the Teensy drives DATA.

## ASSEMBLY NOTES

1 · POWER | One 3.3 V logic rail from the Teensy 3V3 pin, one common GND. Every 3V3 / GND flag is a tap of that pair. The 5V·MOT rail is a separate motor supply sharing only the ground.
2 · DISPLAY | Display SDA / SCL are the module's SPI data and clock: SDA ← Teensy 11 (MOSI), SCL ← Teensy 13 (SCK). Do NOT wire the display to an I²C bus.
3 · IMU STRAPS | PS1 = PS0 = GND selects I²C mode. ADO sets the address: GND → 0x4A (hand), 3V3 → 0x4B (forearm AND thumb tip). The thumb sensor shares bus B with the hand sensor: two addresses, one bus. CS, INT, RST stay open in I²C mode.
4 · MUX STRAPS | A2 A1 A0 = GND GND GND → 0x70 (mux A); A0 → 3V3 → 0x71 (mux B). RST tied to 3V3 (active-low reset held inactive).
5 · BUS A PULL-UPS | One 4.7 kΩ from SDA_Main to 3V3 and one from SCL_Main to 3V3, fitted once at the carrier. No pull-ups on mux channels.
6 · TOUCH (MPR121) | Rides bus A at 0x5A (ADDR → GND): no address clash with the muxes. IRQ is open-drain, active-low → Teensy 3 (INPUT_PULLUP). Keep the 12 electrode runs short; nothing else on a pad.
7 · ENCODERS | All identical, fixed addr 0x36, exactly one per channel (SDx / SCx + 3V3 + GND = 4 wires each). E12 / E13 are spare positions: wiring shown dashed, fit optional.
8 · SERVO BUS | 74HC241 half-duplex on Serial1: TX1 → 2A1, 1Y1 → RX1, DIR (pin 7) → 1OE̅+ 2OE. 10 kΩ pull-up on DATA to 3V3. Single master rule: Teensy or U2D2 on the bus, never both at once.
9 · BUZZER + CROWN | KY-012 is an ACTIVE buzzer: pin 2 HIGH = fixed tone (no PWM). Crown pot wiper on 27/A13; ends to 3V3 and GND; firmware maps the 300..720 raw band to the streamed 0..1000 crown value.

SYMBOL KEY

connected | not connected | n.c. | leave open | NET | named net

Global sheet, rev 2 (supersedes wiring_schematic.svg) · pins, buses and addresses per DATA.md + bringup_12ch v4 · 74HC241 circuit per the standard TTL half-duplex reference · verify strap conventions and module silkscreens before first power-up · motors default to the host U2D2 path (single-master rule)

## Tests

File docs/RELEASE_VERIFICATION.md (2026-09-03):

# Release verification record

This record documents how the public release candidate was assembled and checked, so the
release can be independently reviewed. It describes **file integrity and provenance**. It is
not a medical, mechanical, electrical, or worn-actuation certification.

## Provenance

- CAD was exported on 2026-08-27 from the live Fusion document `Zero_Final_Assembly_Complete`
  version 35. Fusion reported the assembly current, with no out-of-date child references.
- 24 TAKTO-authored components were exported as binary STL and 23 solid components as STEP.
  `BaseSpool` is mesh-only in the current Fusion assembly and is therefore provided as STL only.
  Component versions and assembly quantities are recorded in [`../cad/README.md`](../cad/README.md).
- Only TAKTO-authored mechanical bodies were exported. The hidden personal arm scan and all
  third-party reference models were deliberately excluded, and each STEP file was created from
  an isolated body so it carries no external references.
- Firmware, the two current KiCad projects with their manufacturing outputs, and the operator
  console and bridge were taken from the current working sources. Historical branches were not
  copied.
- **Added after this record was first written:** the public web front end, the AR layer and the
  watch-face engine. They were audited the same way as the tree above — no absolute paths, no
  secrets, no third-party reference models — but the check table below predates them, so treat
  it as covering the original set. **Added 2026-09-02:** the phone companion in
  `software/app/`, an Expo project whose media were captured from its own web target; its
  `node_modules` and capture output are ignored and it carries no other build artefacts. It
  supersedes an earlier Android-only build, which remains unpublished. The sign-language stack
  remains outside this release.

## Checks performed

| Check | Result |
| --- | --- |
| STL integrity, triangle count, file length, finite coordinates, plausible bounds | Passed on every file |
| STEP integrity, complete ISO 10303-21 envelope | Passed on every file |
| STEP headers, author, organization, originating path | Empty; no identity or path leakage |
| Firmware build for Teensy 4.1 | Compiled successfully |
| Bridge byte-compile (Python 3.12) | Passed |
| Bridge simulation, sensor and catalog initialization | 12 synthetic joints, two IMUs, EMG |
| End-to-end WebSocket session against the bridge | Passed. See below |
| Console module graph, every relative import resolves | Passed, no broken imports |
| Console external dependencies | None; no CDN, analytics, or third-party calls |
| Secret patterns, private absolute paths, oversized files, symlinks | None found |
| Published image metadata, author, camera, timestamp, GPS | None present |
| Git history, files added then deleted, oversized blobs, author email | Clean. Re-checked 2026-09-01: no private document has ever been committed on `main`; deleted paths are superseded media only. Commit identities are normalised to a GitHub noreply address before publication |

### End-to-end WebSocket verification

The initial release preparation could not complete this check because the local ports it tried
were already occupied. It has since been run to completion on a free port:

- The bridge started in `--sim` mode and accepted a WebSocket client on the first attempt.
- It broadcast `snap` frames continuously, each carrying 12 joints and 2 motors, alongside
  `takes`, `envs`, `watch_catalog`, and `imu_cfg` messages.
- A representative joint payload was well formed, e.g.
  `{"id": "index_mcp", "deg": 9.03, "ok": true, "calibrated": true}`.

**Fresh-clone re-run, 2026-09-02.** Following the README's own commands on a brand-new clone
(Python 3.12 venv, `--sim`), the bridge crashed on its first state write because the
`SENSORYHAND_STATE_DIR` directory did not exist yet. The earlier check had run in a directory
that already had one. The bridge now creates the directory on start; after the fix the same
clone served `snap` frames with 12 joints and the console loaded from the `http.server`
command. The firmware compile was not repeated for this re-run.

### Scope of these checks

These checks cover **repository integrity**, that the published files are complete, current,
and free of private data. They are not the project's hardware validation.

The device itself has been operated on hardware by the author: the firmware runs on the Teensy,
the Teensy drives the fingers over the Dynamixel bus, and all twelve encoders feed the browser
twin live. That testing predates this release and was not repeated as part of packaging it, so
it is reported in the README under what is verified on hardware, not claimed here as something
this checklist established.

## Excluded from the release

The submitted master's thesis, the personal arm scan, historical CAD and firmware branches,
vendor CAD models, JLCPCB account and order history, the earlier Android-only companion and
the sign-language stack, the AR layer's capture and asset tooling, papers, application
documents, private photos, and build guides containing stale technical claims.

## Third-party material

The vendored Three.js and QR Code Generator files and their MIT terms, and the ORCA hand
spool-station attribution, are recorded in
[`../THIRD_PARTY_NOTICES.md`](../THIRD_PARTY_NOTICES.md).

## Reviewer note

A second reviewer should still inspect the exact repository tree before publication.
Licensing is settled and documented in [`../LICENSE.md`](../LICENSE.md).

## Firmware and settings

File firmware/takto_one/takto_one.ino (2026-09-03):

/*
 * takto_one - TAKTO ONE device firmware (Teensy 4.1)
 * ==================================================
 * The single merged firmware. It replaces the two divergent 2026-07-30
 * branches, which could not both be flashed onto the one Teensy:
 *
 *   Bringup-12ch/bringup_12ch.ino  (v5) -> 14 encoder channels behind two
 *       TCA9548A muxes, THREE BNO085s (hand / forearm / thumb tip), MyoWare
 *       EMG, SD logging, the transparency crown, and the Dynamixel XC330 bus
 *       through the 74HC241 on Serial1: the Teensy owns the motors and runs
 *       the control law itself.
 *   DeviceFirmware/DeviceFirmware.ino  -> the GC9A01A round display, the
 *       dirty-tile DMA renderer, the crown/button/piezo HMI, and the three
 *       the production TAKTO watch interface in watch/.
 *
 * Nothing was dropped in the merge. What CHANGED, and why, is marked
 * "[MERGE]" throughout; the four decisions that matter are:
 *
 *   1. ONE POT, TWO MEANINGS. The crown (pin 27) was the motor blend in one
 *      branch and the carousel's rotary nav in the other. Live at once, a
 *      wearer scrolling the menu would have slewed the assist blend from
 *      transparent to full assist. They are now arbitrated (see "crown
 *      arbitration"), and the crown is presence-checked so an unwired pin can
 *      never fabricate assist authority.
 *   2. THE ASSIST SETPOINT IS SEEDED FROM MEASURED POSITION whenever the
 *      assist law engages, so enabling the motors is always a no-op instead of
 *      a saturated PD step toward servo centre.
 *   3. THE PAINT NEVER STARVES THE CONTROL TICK. The display and the servo
 *      loop share one core, so motorService() is interleaved through every
 *      blocking stretch (encoder sweep, paint, SD, scans). 'M,s' reports the
 *      overruns honestly; the servo-side 100 ms Bus Watchdog is the backstop.
 *   4. THE STREAM NOW MATCHES ITS OWN HEADER. v5 advertised servo telemetry
 *      it never emitted. v6 emits it, plus a crown-presence flag. Appending
 *      only: every pre-existing field index is unchanged.
 *
 * ARCHITECTURE (see Bringup-12ch/WIRING_MASTER_PLAN.md; verify J41 against KiCad):
 *   Encoders : up to 14 AS5600 (addr 0x36) behind 2x TCA9548A muxes
 *              MUX_A @ 0x70 channels 0..7  -> encoder channels 0..7
 *              MUX_B @ 0x71 channels 0..5  -> encoder channels 8..13
 *              Mux main I2C bus  -> Teensy Wire  (SDA 18 / SCL 19), 400 kHz
 *   IMUs     : 3x BNO085. Hand 0x4A on Wire1 (17/16); forearm 0x4B on Wire2
 *              (25/24); THUMB TIP 0x4B on Wire1,
 *              routed through the palm PCB
 *              (the BNO085 has only two addresses, so the thumb shares the
 *              hand's bus at the other address - the reentrant driver was
 *              built for exactly this; adjust IMU_WIRE/IMU_ADDR index 2 if the
 *              bench routing differs).
 *   Motors   : 2x XC330-M181-T, Protocol 2.0, half-duplex through a 74HC241 on
 *              Serial1 (pins 0/1), direction on pin 7 (HIGH = transmit).
 *   Display  : GC9A01A 240x240 round panel on SPI0, CS 10 / DC 9 / RST 8.
 *   HMI      : crown pot pin 27 (A13), button pin 5, piezo pin 2.
 *   EMG      : MyoWare envelope on pin 14 (A0).
 *   SD       : Teensy 4.1 built-in socket (BUILTIN_SDCARD, SDIO - not SPI).
 *
 * PIN MAP - checked for conflicts across the merge (this is the whole board):
 *   0,1   Serial1 RX/TX (Dynamixel)      | 2   piezo
 *   5     button                          | 7   74HC241 direction
 *   8,9,10 display RST/DC/CS              | 11,12,13 SPI0 MOSI/MISO/SCK
 *   14    EMG (A0)                        | 16,17 Wire1 SCL/SDA (hand + thumb)
 *   18,19 Wire SDA/SCL (encoder muxes)    | 24,25 Wire2 SCL/SDA (forearm)
 *   27    crown pot (A13)                 | SDIO built-in SD
 *   No pin is claimed twice. SPI0 carries the panel only; SD is SDIO.
 *
 * SERIAL MENU (115200 baud, send a single letter):
 *   s = re-scan the buses and print the wiring report
 *   A = full I2C scan (what actually ACKs, and where)
 *   c = run a 12 s range-of-motion calibration (flex everything, slowly)
 *   r = start / stop an SD recording (toggles - bench-human convenience)
 *   b = START recording  (explicit, idempotent - what the host bridge sends)
 *   e = STOP  recording  (explicit, idempotent - what the host bridge sends)
 *   v = print the version banner "# ver bringup_12ch <n>" (host handshake)
 *   j = live stream ON   k = live stream OFF
 *   R = quiet hot-plug rescan (the host bridge sends this)
 *   T = paint-cost + loop-rate report (the display's frame budget)
 *   ? = help
 *   D,<screen>,<elapsedSec>,<mot>\n   host-pushed device-screen state
 *   W,<face>,<colorway>\n             host-pushed watch-face selection
 *   M,...\n                           motor commands (see below)
 * Every one of D/W/M is buffered as a WHOLE LINE and dispatched on '\n', so
 * payload bytes can never alias the single-letter commands above and no
 * parseInt() can stall the servo tick.
 *
 * MOTOR COMMANDS (all optional; the bus is untouched until M,t,1):
 *   M,t,<0|1>        release / TAKE the servo bus. TAKE first LISTENS and refuses
 *                    if another master is driving DATA (single-master: disconnect
 *                    the U2D2); then auto-baud scans (4 Mbps first), requires BOTH
 *                    motors present, qualifies the link (repeated round-trips),
 *                    checks the model, and connects torque OFF (compliant)
 *   M,e,<0|1>        torque off / ON (on-path configures current mode, RDT 0 us,
 *                    current limit, arms the Indirect feedback block, SEEDS the
 *                    assist setpoints from measured position, then energizes)
 *   M,m,<0|1|2>      mode: 0 idle, 1 RUN (blended transparency<->assist), 2 direct
 *   M,a,<-1|0..1000> assist blend override; -1 = follow the physical crown
 *   M,c,<id>,<mA>    direct current setpoint (mode 2), clamped to +/-44 mA (= 10 N)
 *   M,p,<id>,<deg>   assist position setpoint (mode 1), servo horn degrees
 *   M,k,<kp>,<kd>    assist gains [mA/rad, mA/(rad s^-1)]
 *   M,f,<visc>,<coul> transparency friction feed-forward [mA/(rad s^-1), mA]
 *   M,s              print servo-loop + bus statistics (human)
 *   M,u              one-time servo EEPROM upgrade: baud -> 4 Mbps, RDT -> 0 us
 *   M,b[,N]          bus benchmark: N ticks with 0x82 then 0x8A at the current baud
 *   Feedback per tick: ONE Fast Sync Read 0x8A (position + current + velocity +
 *   hardware-error, one turnaround) + ONE Sync Write (goal current); inner loop
 *   up to 2 kHz at 4 Mbaud. Watchdog: 600 ms without any M COMMAND line (v14:
 *   the 50 Hz 'M,j' joint telemetry no longer counts as liveness) demotes
 *   direct-current and jog to RUN, re-seeds the assist setpoint from measured
 *   position, and returns blend authority to the crown - the device degrades to
 *   the compliant (transparent-leaning) state, never to a locked one.
 *   MODE 4 IS THE EXCEPTION (v14): it drives a worn finger from a host-computed
 *   target, so host silence DE-ENERGIZES it (faultCause 7) rather than demoting
 *   it to a crown-blended hold that would keep pushing after the host died.
 *   Safety: any Hardware Error Status bit or MOTOR_ERR_TRIP consecutive missed
 *   reads -> torque off (counted, recoverable with M,e,1).
 *
 * LIVE STREAM (for the web console bridge): while streaming is ON the sketch
 * emits, at SAMPLE_HZ, one line per sample:
 *   S,<t_ms>,<enc00>..<enc13>,<h_qw,h_qx,h_qy,h_qz>,<f_qw,f_qx,f_qy,f_qz>,
 *     <imu0live>,<imu1live>,<emg_env>,<emg_rms>,<emg_present>,<crown_0..1000>,
 *     <t_qw,t_qx,t_qy,t_qz>,<imu2live>,<mflags>,<m0_pos>,<m0_vel>,<m0_ma>,
 *     <m1_pos>,<m1_vel>,<m1_ma>,<crown_live>
 * (fields are append-only across firmware versions: v3 ended at crown, v4
 *  appends the thumb-tip quaternion + live flag, v5 DOCUMENTED servo telemetry,
 *  v6 actually EMITS it and appends crown_live, v7 the full IMU set, v9 the
 *  motor fault diagnostics, v14 one seaState byte at the very end. mflags =
 *  taken | torque<<1 | mode<<2 | fault<<5 (bit 4 is mode 4, the SEA loop);
 *  seaState = zeroed | armed<<1 | directions<<2 | jointFresh<<3; pos deg /
 *  vel dps / mA; crown_live = 1 present, -1 no crown wired. Hosts parse by
 *  index and must tolerate a short line.)
 * Encoders that did not answer at the last scan stream -1. Re-scan ('s') after
 * you wire a new channel so it starts streaming. Scan/calib/record still work.
 *
 * Libraries: Wire, SD, EEPROM, SPI are built in; install "Adafruit GFX" and
 * "Adafruit GC9A01A" via Library Manager. The BNO085 driver is tiny_bno085.h
 * here (reentrant, three instances) - the Adafruit library is single-instance
 * and cannot do this.
 * No warranty: compile, flash, then follow the bring-up order in
 * firmware/README.md with the device on the bench, motor power disconnected,
 * before trusting a joint.
 */

#include <Wire.h>
#include <SD.h>
#include <EEPROM.h>        // watch-face selection survives a power cycle
#include "tiny_bno085.h"   // reentrant per-instance driver (Adafruit lib is single-instance)
#include "tiny_dxl.h"      // minimal Protocol 2.0 master (74HC241 half-duplex on Serial1)
#include <SPI.h>
#include <Adafruit_GFX.h>
#include <Adafruit_GC9A01A.h>
#include <Fonts/FreeSansBold24pt7b.h>
#include <Fonts/FreeSansBold12pt7b.h>
#include <Fonts/FreeSans9pt7b.h>
#include "firmware_ui.h"   // dirty-tile + DMA panel push, crown/button/piezo HMI

// ---- configuration ---------------------------------------------------------
#define MUX_BUS      Wire          // encoders' mux main bus (pins 18/19)
// Each BNO085 gets its OWN I2C bus where it can (kills the two-device clock-
// stretch contention). The thumb is the second address on Wire1.
// The verified wearable, open release and Bringup-12ch firmware all use the
// strapped forearm module at 0x4B. A later 0x4A edit probed an empty address
// after flashing and left the forearm stream zero-filled/offline.
TwoWire* const IMU_WIRE[3] = { &Wire1, &Wire2, &Wire1 };   // hand, forearm, thumb
const uint8_t  MUX_ADDR[2] = {0x70, 0x71};
const uint8_t  CH_PER_MUX  = 8;        // TCA9548A has 8 channels
const uint8_t  N_CHANNELS  = 14;       // encoder channels in use (0..13)
const uint8_t  AS5600_ADDR = 0x36;
const uint8_t  REG_STATUS  = 0x0B;
const uint8_t  REG_AGC     = 0x1A;     // automatic gain, rails when the magnet is wrong
const uint8_t  REG_MAG_HI  = 0x1B;     // CORDIC magnitude (0x1B:0x1C)
const uint8_t  AS_MD       = 0x20;     // STATUS bit 5: magnet detected
const uint8_t  AS_ML       = 0x10;     // STATUS bit 4: magnet too weak
const uint8_t  AS_MH       = 0x08;     // STATUS bit 3: magnet too strong
// Declared up here on purpose: the .ino auto-prototype pass hoists function
// prototypes to the top of the file, so a struct used in a signature must be
// visible before them or the build fails with "does not name a type".
struct MagStat { bool ok; uint8_t status; uint8_t agc; uint16_t mag; };
const uint8_t  REG_ANGLE_HI= 0x0E;
// NOTE: these addresses are duplicated in the bno[] constructors below. The
// scan report reads IMU_ADDR and the driver reads its own copy, so if the two
// ever disagree the wiring report lies about what the driver is talking to.
// Change both or neither.
uint8_t        IMU_ADDR[3] = {0x4A, 0x4B, 0x4B};   // forearm default 0x4B on Wire2;
                                                   // runtime probe also accepts 0x4A
const char*    IMU_NAME[3] = {"hand", "forearm", "thumb"};
const float    SAMPLE_HZ   = 50.0f;
const uint8_t  EMG_PIN     = 14;       // MyoWare ENVELOPE output on A0; oversampled -> env + rms
// [MERGE] v6: the S-line finally carries the servo telemetry v5 documented, plus
// crown_live. Both are APPENDED, so every pre-existing field index is unchanged
// and an old host simply does not look at them.
const uint8_t  FW_VERSION  = 15;       // v15 adds the bounded mode-2 breakaway kick
                                       // (M,K) so direction identification can exceed
                                       // the sustained cap briefly; the follow law cannot
                                       // v14 reports SEA readiness so the host cannot
                                       // claim an arm the device refused; mode 4 now
                                       // de-energizes on host silence instead of
                                       // demoting to a crown-blended hold
                                       // v13 adds the calibration-gated two-DOF SEA mode
                                       // v7: full IMU set appended to the S-line
                                       // (linear accel, accel, gyro, mag, gravity,
                                       // game rotation vector, calibration accuracies)
                                       // v8: watch-face/display changes of 2026-08-10;
                                       // bumped so the host can tell this build from v7
const uint8_t  N_IMU       = 3;        // hand, forearm, thumb tip
const uint32_t IMU_STALE_MS = 500;     // no rotation report this long = the sensor silently died

// Crown potentiometer (pin 27 = A13, same wiring + calibrated active band as
// the v9 dashboard: the pot's usable travel is 300..720 of the 10-bit range).
// Continuous transparency control, Apple-crown style: low = fully transparent
// (device renders zero force), high = fully assisted. Streamed as 0..1000.
const uint8_t  POT_PIN         = 27;
const int      POT_ACTIVE_LOW  = 300;
const int      POT_ACTIVE_HIGH = 720;
// [MERGE] crown PRESENCE. An unwired analog pin floats, and a floating pin fed
// into the motor blend is fabricated authority: the console would show a crown
// that is not there and the assist term would follow ADC noise. The crown counts
// as present only after the raw ADC has sat inside the active band (plus a
// margin for pot tolerance) for CROWN_PRESENT_FRAMES consecutive frames, and
// leaves that state the instant it goes out of band. Absent -> crownFilt = -1 ->
// blend 0. The fail-safe direction is ALWAYS toward transparency, never assist.
// Honest limit: a floating pin that happens to sit inside the band still reads
// as present. This gate removes the obvious failure, not every conceivable one -
// the real protection is that assist requires an explicit M,e,1 and is capped.
const int      POT_PRESENT_LO  = 250;
const int      POT_PRESENT_HI  = 790;
const uint8_t  CROWN_PRESENT_FRAMES = 10;   // 0.2 s at 50 Hz

// ---- state -----------------------------------------------------------------
bool     chLive[N_CHANNELS];           // did this encoder answer at scan?
float    chMin[N_CHANNELS], chMax[N_CHANNELS];
float    frameDeg[N_CHANNELS];         // ONE acquisition per frame, shared by SD row + S-line + faces
float    romLo[N_CHANNELS], romHi[N_CHANNELS];   // running range, for face normalization
bool     chSampled = false;
// The rig surrounds the BNO085s with neodymium magnets, so the absolute
// rotation vector (0x05) can stall or jump while trying to reconcile an
// impossible magnetic field.  Game rotation vector (0x08) uses gyro + accel
// only.  Selecting it here also makes imuFreshMs/liveness follow the quaternion
// the twin actually consumes, rather than letting a stale 0x05 pose stay live.
TinyBNO085 bno[3] = {
  TinyBNO085(&Wire1, 0x4A, TinyBNO085::RPT_GAMEROTVEC),  // hand    - Wire1 (17/16)
  TinyBNO085(&Wire2, 0x4B, TinyBNO085::RPT_GAMEROTVEC),  // forearm - own bus (25/24)
  TinyBNO085(&Wire1, 0x4B, TinyBNO085::RPT_GAMEROTVEC)   // thumb tip - Wire1, 0x4B
};
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
void loop() {
  motorService();   // servo control tick (no-op until the bus is taken with M,t,1)
  // Drain everything pending (a backlog builds during the deliberate blocking
  // commands). Line-oriented input (D/W/M) is buffered as a unit so payload
  // bytes can never alias the single-letter menu commands.
  while (Serial.available()) {
    char c = Serial.read();
    if (discardLine) { if (c == '\n') discardLine = false; continue; }
    if (lnTag) {                            // accumulate a whole line, dispatch on newline
      if (c == '\n') { lnBuf[lnLen] = 0; handleHostLine(lnTag, lnBuf); lnTag = 0; lnLen = 0; }
      else if (lnLen >= sizeof(lnBuf) - 1) {  // over-long: dispatch what we have, swallow the tail
        lnBuf[lnLen] = 0; handleHostLine(lnTag, lnBuf); lnTag = 0; lnLen = 0; discardLine = true;
      } else lnBuf[lnLen++] = c;
      continue;
    }
    if (c == 'D' || c == 'W' || c == 'M') { lnTag = c; lnLen = 0; lnBuf[lnLen++] = c; }
    else if (c == 's') scanAll();
    else if (c == 'A') fullScan();
    else if (c == 'c') calibrate();
    else if (c == 'r') recToggle();                       // human toggle
    else if (c == 'b') { if (!recording) recToggle(); }   // host: explicit start (idempotent)
    else if (c == 'e') { if (recording)  recToggle(); }   // host: explicit stop  (idempotent)
    // The banner token stays "bringup_12ch": it IS the host handshake string the
    // bridge greps for (teensy_bridge.py "# ver"), so renaming it would silently
    // demote every console to legacy-firmware behaviour.
    else if (c == 'v') Serial.printf("# ver bringup_12ch %u\n", FW_VERSION);
    else if (c == 'j') { streaming = true;  Serial.println(F("# stream ON")); }
    else if (c == 'k') { streaming = false; Serial.println(F("# stream OFF")); }
    else if (c == 'R') detectAll();   // quiet hot-plug rescan (host bridge sends this)
    else if (c == '?') printHelp();
    else if (c == 'T') {                    // paint-cost report (frame budget)
      uint32_t win = millis() - statsT0;
      if (win < 1) win = 1;
      Serial.printf("# paint face=%s/%s last=%luus max=%luus mean=%luus "
                    "paints=%lu (%.1f/s) samples=%lu (%.1f/s) loop=%.0f/s window=%lums "
                    "tiles=%lu panel_runs=%lu panel_last=%luus panel_max=%luus slow=%lu "
                    "cadence=%lums interact=%lums deferred=%lu pending=%d rot=%d sync=1\n",
                    watch::active()->id(),
                    watch::active()->colorway(watch::curColorway[watch::curFace]).id,
                    (unsigned long)paintLastUs, (unsigned long)paintMaxUs,
                    (unsigned long)(paintCount ? paintSumUs / paintCount : 0),
                    (unsigned long)paintCount, paintCount * 1000.0f / win,
                    (unsigned long)screenSamples, screenSamples * 1000.0f / win,
                    loopPasses * 1000.0f / win, (unsigned long)win,
                    (unsigned long)uiR.pushed, (unsigned long)uiR.runs,
                    (unsigned long)uiR.lastWriteUs, (unsigned long)uiR.maxWriteUs,
                    (unsigned long)uiR.slowWrites,
                    (unsigned long)WATCH_PRESENT_FRAME_MS,
                    (unsigned long)WATCH_PRESENT_INTERACT_MS,
                    (unsigned long)screenDeferredBusy, uiR.pending ? 1 : 0,
                    TFT_ROTATION);
      paintMaxUs = 0; paintCount = 0; paintSumUs = 0; loopPasses = 0;
      screenSamples = 0; screenDeferredBusy = 0;
      statsT0 = millis();
    }
  }
  motorService();   // keep the control tick alive after draining a serial backlog
  loopPasses++;
  imuService();
  Ev ev = uiIn.poll();                    // crown + button (detents tick the piezo)
  if (ev != Ev::NONE) uiHandleEvent(ev);
  screenService();                        // presentation <=7.7 Hz (crown <=9.6 Hz)
  uiR.task();                             // ships <=1 coherent synchronous run per pass
  motorService();
  // oversample the MyoWare envelope (pin 14) at ~1 kHz between the 50 Hz frames
  uint32_t nowU = micros();
  if (nowU - emgLastU >= 1000) {
    emgLastU = nowU;
    uint16_t v = analogRead(EMG_PIN);
    emgSum += v; emgSumSq += (uint32_t)v * v; emgCount++;
  }
  const uint32_t PERIOD_MS = (uint32_t)(1000.0f / SAMPLE_HZ);
  uint32_t now = millis();
  if (now - lastSample >= PERIOD_MS) {
    // Advance by the period so the average rate is exactly SAMPLE_HZ (a plain
    // `lastSample = now` slips by the loop latency every frame). After a real
    // stall (SD flush, calibrate) resync instead of bursting catch-up frames:
    // bunched rows would be worse data than honestly missing rows.
    lastSample += PERIOD_MS;
    if (now - lastSample >= PERIOD_MS) lastSample = now;
    // reduce the EMG oversample to envelope (mean) + RMS, then reset the accumulator
    emgHave = (emgCount > 0);
    if (emgHave) {
      emgEnv = (float)emgSum / (float)emgCount;
      emgRms = sqrtf((float)emgSumSq / (float)emgCount);
    } else { emgEnv = 0.0f; emgRms = 0.0f; }
    emgSum = 0; emgSumSq = 0; emgCount = 0;
    crownSample();                  // presence-gated, carousel-arbitrated blend
    // ONE sensor acquisition per frame, shared by the SD row, the S-line AND the
    // faces. [MERGE] the sweep now runs whenever anything consumes it - and the
    // on-device screen always does, which is why the device shows real finger
    // motion standing alone instead of only while a host is streaming.
    readAllChannels(frameDeg);
    noteChannelRange();
    motorService();                 // the 50 Hz frame is the longest blocker
    if (recording) recWrite(now);
    if (streaming) emitStream(now);
    motorService();
  }
}

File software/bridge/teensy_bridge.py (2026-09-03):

#!/usr/bin/env python3
"""
teensy_bridge.py - the TAKTO ONE ecosystem host bridge.

Connects the TAKTO operator console to the Teensy over
ws://<host>:8765/ws. Shared state, calibration and recorded sessions are owned
by this process and broadcast to connected consoles at 60 Hz.

Data sources (pick one):
  --port /dev/cu.usbmodemXXX   live Teensy (bringup_12ch stream, 'j' = ON):
      S,<t_ms>,<enc00..enc13>,<h_qw..h_qz>,<f_qw..f_qz>,<imu0live>,<imu1live>[,emg]
      Encoders/IMUs the firmware reports absent are sent ok:false (honest);
      motors stay host-owned and un-bridged on real hardware (never faked).
  --sim   no hardware at all: a 50 Hz synthetic full-system scene (12 joints,
      2 IMUs, EMG through the real activation filter, N simulated motors) runs
      through the same calibration and snapshot pipeline.

Run:
    python teensy_bridge.py --port /dev/cu.usbmodemXXXX
    python teensy_bridge.py --sim
Then open the console URL documented in software/README.md.
"""
import argparse, asyncio, copy, glob, json, math, os, re, threading, time, sys
from collections import deque

sys.path.insert(0, os.path.dirname(os.path.abspath(__file__)))
import tendon

# Snapshot broadcast rate. 60 Hz outruns the device's 50 Hz sampling, so a
# fresh sample never waits more than one 16.7 ms tick to ship (at 30 Hz the
# mean queueing delay alone was ~17 ms). Overridable: --hz / bench_replay.
# Latency notes: asyncio TCP transports have TCP_NODELAY on by default
# (CPython) and the hub serializes each snapshot ONCE for all clients.
HZ = 60
WS_PORT = 8765               # advertised in link.port for QR pairing

# Every persisted file (calibrations, home pose, take library) lives here.
# Tests set SENSORYHAND_STATE_DIR to an isolated dir so runs never touch the
# real bench calibration in ~.
STATE_DIR = os.environ.get("SENSORYHAND_STATE_DIR", os.path.expanduser("~"))
# A fresh checkout has no state directory yet; the first atomic write would
# otherwise fail on the .tmp file before the bridge ever serves a frame.
os.makedirs(STATE_DIR, exist_ok=True)


def _write_json_atomic(path, obj):
    """Every state write goes through tmp+rename (os.replace is atomic on
    POSIX), so a crash mid-write can never leave a half-written index or
    calibration file for the next start to trip over."""
    tmp = path + ".tmp"
    with open(tmp, "w") as f:
        json.dump(obj, f)
    os.replace(tmp, path)


def _quarantine_corrupt(path, err, tag):
    """A corrupt index must never be silently forgotten: keep the evidence and
    say so loudly. Data files stay on disk; _next_state_id() keeps counting
    from them, so a reset index can never recycle an ID over old data."""
    dest = "%s.corrupt-%d" % (path, int(time.time()))
    try:
        os.replace(path, dest)
    except OSError:
        dest = "(could not move it)"
    print(f"[{tag}] CORRUPT index {path}: {err} -> quarantined to {dest}; "
          "data files untouched, IDs continue from the files on disk")

# Rolling capture-diagnostics log (2026-07-20): clients ship their full scan
# diagnostic ({cmd:"diag"}) at every transition, and every env_save - success
# OR reject - is appended too. serve_quest.py's HTTP beacon writes the same
# file, so ONE file reconstructs any capture attempt (the round-1 failure was
# exactly that nothing was written anywhere). Trimmed so it never grows
# unbounded.
DIAG_LOG = os.path.join(STATE_DIR, ".sensoryhand_diag.log")
DIAG_LOG_MAX_LINES = 4000


def diag_append(entry):
    """Append one JSON line to the diag log; trim the file when it gets long.
    Never raises: diagnostics must not take the bridge down."""
    try:
        entry = dict(entry)
        entry["t_srv_ms"] = int(time.time() * 1000)
        with open(DIAG_LOG, "a") as f:
            f.write(json.dumps(entry) + "\n")
        if os.path.getsize(DIAG_LOG) > 8 * 1024 * 1024:
            with open(DIAG_LOG) as f:
                lines = f.readlines()[-DIAG_LOG_MAX_LINES:]
            with open(DIAG_LOG, "w") as f:
                f.writelines(lines)
    except Exception as e:
        print("[diag] could not append log:", e)

try:
    import serial  # pyserial
except Exception as e:
    print("MISSING pyserial:", e); sys.exit(3)
try:
    import websockets
except Exception as e:
    print("MISSING websockets:", e); sys.exit(3)

N_CH = 14
FINGERS = ["index", "middle", "ring", "pinky"]
SEGMENTS = ["mcp", "pip", "dip"]

# encoder channel -> joint name. Default order: ch0..11 = the 4 fingers x 3
# segments (mcp,pip,dip), ch12/13 spare. Adjust here once calibration ('c')
# tells you which channel actually moves for which joint.
JOINT2CH = {}
for fi, f in enumerate(FINGERS):
    for si, seg in enumerate(SEGMENTS):
        JOINT2CH[f + "_" + seg] = fi * 3 + si

CH2JOINT = {ch: name for name, ch in JOINT2CH.items()}   # reverse: encoder channel -> joint name

# ---- wired-finger encoder -> DOF mapping + live zeroing ---------------------
# The one wired finger's 3 encoders drive its MCP (2 DOF) and PIP (1 DOF). The
# twin reads, per finger (see twin.js render): <f>_mcp = MCP ABDUCTION (signed,
# ~+-16 deg, 0 = straight), <f>_pip = MCP FLEXION (8 = open .. ~60 curl), <f>_dip
# = PIP FLEXION (8 = open .. curl). So map each wired channel to a DOF, sign and
# scale (adjust after watching each joint move), and zero it to a live neutral.
WIRED_FINGER = "index"
# channel -> (dof, sign) per the wiring the user reported: ch10 = MCP side-to-side
# (abduction), ch8 = MCP up/down (flexion), ch9 = PIP up/down (flexion).
ENC_DOF = {
    10: ("abduct",  +1.0),
    8:  ("mcpflex", +1.0),
    9:  ("pipflex", +1.0),
}
# Real AS5600 samples are absolute magnet angles, not anatomical joint angles.
# Only channels in ENC_DOF have a measured channel -> DOF mapping today. The
# simulator and the explicit bench replay opt in when their arrays are already
# joint-space degrees. This prevents an uncalibrated 230 degree sensor reading
# from becoming a 230 degree finger pose hidden only by a renderer clamp.
ENC_JOINT_SPACE_DIRECT = False
DOF_SEG = {"abduct": "mcp", "mcpflex": "pip", "pipflex": "dip"}
ABDUCT_SCALE = 1.0                    # deg abduction per deg encoder (tune from side-to-side)
# Twin flexion range = the MECHANICAL ROM (thesis hard stops): open 0 deg,
# MCP flexion closes at 90, PIP flexion at 110 (per-DOF closed map below).
FLEX_OPEN, FLEX_CLOSED = 0.0, 90.0
DOF_CLOSED = {"mcpflex": 90.0, "pipflex": 110.0}
# Two-point flexion calibration: raw at the straight-EXTENDED pose (open) and the
# fully-CONTRACTED pose (closed) per channel. Mapping raw between them gives each
# flexion joint its direction AND travel for free (no manual sign/scale needed).
ENC_OPEN = {}    # channel -> raw at straight/extended reference
ENC_CLOSED = {}  # channel -> raw at contracted reference
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

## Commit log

2026-09-03 TAKTO ONE 1.0.0
    A wearable hand exoskeleton that reads, assists and records the human hand.
    Twelve sensed joints, three inertial frames, 50 Hz telemetry, onboard capture
    to SD, and a browser console with a live 3D twin.
    This is the first public release. Mechanism, electronics, firmware, the phone
    companion, the AR layer and the web console are all here, with the build guide,
    wiring, bill of materials and the boards needed to make one.
    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
    [Zero_Palm_V1-B_Cu.gbr, Zero_Palm_V1-B_Mask.gbr, Zero_Palm_V1-B_Paste.gbr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]
2026-09-03 Console: unshred the internals and light the screen there too
    The operator console is a separate app from the public front end and kept its
    own copy of the twin, so it never received either fix. That matters more than
    it sounds: the README's quickstart points at this app, so the first thing
    anyone ran after cloning showed the torn geometry and the dark display.
    Internals go from 9,469 triangles to 37,937 and motors from 5,636 to 31,840,
    using the same protected rebuild the front end uses. The round display now
    generates planar UVs and carries the device's real UI from device_screen.js,
    with the focus cue moved from hue to intensity so the mapped face survives.
    The console keeps its own war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
2026-09-04 Make both films play on mobile, not just desktop web
    A bare user-attachments URL only becomes a player in GitHub's web renderer.
    The mobile app does not run that conversion, so both films showed as raw blue
    links: the two things most worth seeing were the two things a phone could not
    watch.
    They are explicit <video> tags now, each wrapping a linked poster frame taken
    from that film's own first frame. That is HTML's own fallback mechanism, so
    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
2026-09-04 Both README films were clicking through to 404
    On a public repository, both video blocks rendered a poster that linked to a
    dead github.com/user-attachments URL. Anyone arriving from a link got a 404
    from the top of the page.
    Two faults, compounding. The films had been wrapped in <video> tags, which the
    comment directly above the first one warns against: GitHub's sanitiser strips
    <video>, so the inline player never rendered and only the <a><img> fallback
    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
2026-09-04 Films play on the phone too
    The posters pointed at the in-repo .mp4 files. That opens GitHub's player on
    the desktop site, but in the GitHub mobile app a tap on that link does
    nothing useful, so on a phone both films were dead.
    Both posters now link to GitHub attachment URLs, which is the one form that
    works in both places: a poster image renders on desktop and in the app, and
    the attachment is served as video/mp4 with no download disposition, so the
    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
2026-09-05 cad/README: how the parts go together, and why the assembly is not here yet
    A student who found the STEP files wrote to ask how they fit, because nothing
    in cad/ pointed anywhere. The 24-page illustrated build guide answers most of
    his question and has been in docs/ the whole time; this folder now sends the
    reader there, chapter by chapter, with the two superseded statements flagged.
    Two things the filenames do not say are said now. The fingers are numbered as
    anatomical digits, so finger2 is the index and finger5 the little finger. And
    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
2026-09-05 Point the CAD readme at the assembly download
    The previous text promised an assembly export and explained why it did not
    exist yet. It exists now, attached to the v1.0.0 release: four finger
    subassemblies and the palm stack, each as Fusion native and STEP.
    Says which format to open and why. The f3d carries the real component names,
    the history and the joints, and is the source in the preferred form for
    modification that CERN-OHL-S-2.0 asks for. The STEP is exact geometry in exact
    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
2026-09-05 Publish every part as a Fusion native, not just the assemblies
    The assemblies showed how parts fit together but still left the parts
    themselves as dead geometry: STEP and STL can be measured, not re-dimensioned.
    All 29 individual components now ship as .f3d, each carrying its own sketches,
    parameters and feature history, named to match the existing stl/ and step/
    files so they pair without guesswork.
    This is what CERN-OHL-S-2.0 means by source in the preferred form for
    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
2026-10-01 Contact: switch to sebastianmolano.eng@gmail.com
    The project's public contact address changes; the old personal address
    is retired from the README and the website's contact button.
2026-10-02 Website: the takto.one source, as deployed
    software/web now matches what takto.one serves: the product page (site.css, the entry view,
    the product renders and the 360-degree frames, the new logo), the console and its modes, the
    legal pages and consent, and the build tools (build-site.mjs, bake-web-glb.mjs).
    software/brand/brand.py draws the logo.
    The twin's stage tag and the presentation pill no longer say LIVE over simulated data: like
    the SIMULATED DATA badge, they follow the data source.
    The firmware and the bridge in this release are unchanged. On public origins the site runs
    its built-in, labelled simulation.
2026-10-02 README: the boards and the wiring up front, the new website, verified facts only
    The two custom boards and the full wiring move up, right after "What it already does", with
    the palm carrier's documented SDA/SCL erratum and the JLCPCB order.
    The website section shows takto.one and points at its source in software/web.
    Corrections, so every claim matches the repository and the bench:
    - one watch face ships (thesis, three colourways); rams and ferro are design studies
    - one finger is driven, by two XC330 servos; the design takes eight
    - four encoder channels are down after a wiring fault, so eight of twelve joints read today
    - the EMG intent figure is simulation, and says so
    - this release st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
2026-10-03 README: loads on phones, stills for the loops and lighter images
    GitHub loads every image in a README at once and strips loading="lazy", so a phone had to
    pull 20.2 MB before the page settled, 16 MB of it five animated GIFs. Each loop now sits in
    a <picture> that gives phones, tablets and reduce-motion readers a still frame, and a tap
    opens the loop; desktops still get the GIFs. The large stills are re-encoded: hero,
    colourways, encoder board and the watch-face sheet as JPEG, the wiring and the EMG figure as
    128-colour PNG in place. A phone now downloads 1.4 MB. The originals stay in docs/media for
    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
2026-10-06 README: the board notes and the directions read on a phone
    On a phone the board table squeezed its two paragraphs into narrow
    cells that ran past the screen edge, and the directions table became a
    1,400 px column of one-word lines. The board notes now sit under the
    renders, and the directions are a list.
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2026-10-14 README: each clip in its own section, full width
    The worn clip and the AR recording no longer share a table: each has its
    own section under the intro, the worn loop at 400 px, the AR loop at full
    width. The AR caption now says what drives the twin: the encoders and
    the two IMUs, nothing from the headset.
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2026-10-14 README and BOM: designed for ten motors, built with two
    TAKTO ONE was designed from the start for ten servos, two per digit
    (eight for the long fingers, two for the thumb): ten spool bays, and a
    bus and BOM laid out for them. The self-funded prototype is built with
    two, on one finger; the limit is the budget, not the design. The machine
    table, the build comparison, the status section, the FAQ and the BOM
    scope now say so, and the BOM no longer says the device controls eight
    motors today.
2026-10-17 Docs: plain wording across the README and docs, and a few fact fixes
    Rewrote the README, BOM, CONTRIBUTING, the licence summary and the docs,
    CAD, electronics, software and watch-face READMEs in a plainer voice.
    Media blocks, numbers, links and code are unchanged.
    Fact fixes found on the way:
    - The SD log writes one row per frame, so it runs at SAMPLE_HZ. The old
    README said logging could run faster than the console.
    - The bridge names each finger's channels _mcp/_pip/_dip by encoder
    position; they measure MCP abduction, MCP flexion and PIP flexion.
    There is no DIP sensor.
    - TAKTO-SIGN: the capture and live-recognition pages are in software/web;
    the recogniser, its training code and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
2026-10-17 Watch docs: match the firmware
    The watch-face docs still described three switchable faces. The firmware
    registers only the thesis face (FACE_COUNT = 1, one face in catalog.json),
    so W,1,0 and W,2,0 are refused. Ferro and Rams stay in the source for
    reference. The four docs in firmware/takto_one/watch/docs now say so, and
    the runbook switches colorways instead of faces.
    Other fixes, each checked against the source:
    - Rams draws four per-finger bars, not twelve joint bars. Its spec is the
    header of watch/face_rams.h, not faces/face_rams.h, and that header
    makes the centre numeral the primary reading.
    - In the Rams spacing pass every state but stop got cheaper. Stop stayed
    at 0.39x.
    - Th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
2026-10-21 README: the build guide's steps 16 and 17 under the build steps
    Page 14 of docs/build-guide.pdf (fit the EMG module, then lower the case
    over the device), rendered from the PDF, links to the guide. The build
    steps table gains the assembly row it was missing.

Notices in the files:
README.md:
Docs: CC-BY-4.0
